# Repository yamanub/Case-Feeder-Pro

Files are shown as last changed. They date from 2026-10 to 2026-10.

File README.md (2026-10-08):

# Case Feeder Pro

Firmware for an automatic brass case feeder, a bullet feeder, or both run
side by side from one controller, with a touchscreen to control them.

- **Controller:** BigTreeTech SKR Pico V1.0 (RP2040). It drives the feeder
  motors, watches the part sensors, detects and clears jams, and stores
  the settings.
- **Touchscreen:** LCDWiki ES3C28P 2.8" ESP32-S3 display. It shows each
  feeder's state, speed and rate, sounds alerts, and holds the settings.

## The feeders

### Case feeder

<p>
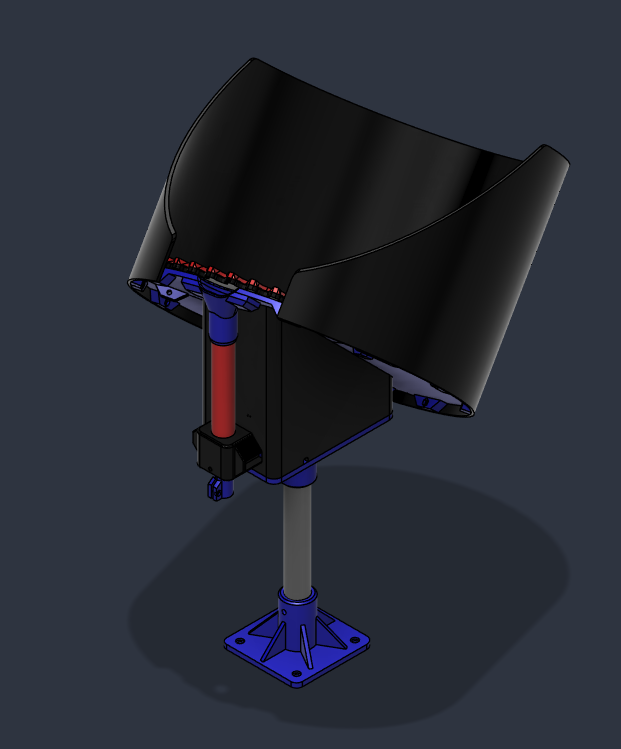
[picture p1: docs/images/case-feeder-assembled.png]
Case feeder on its stand
  
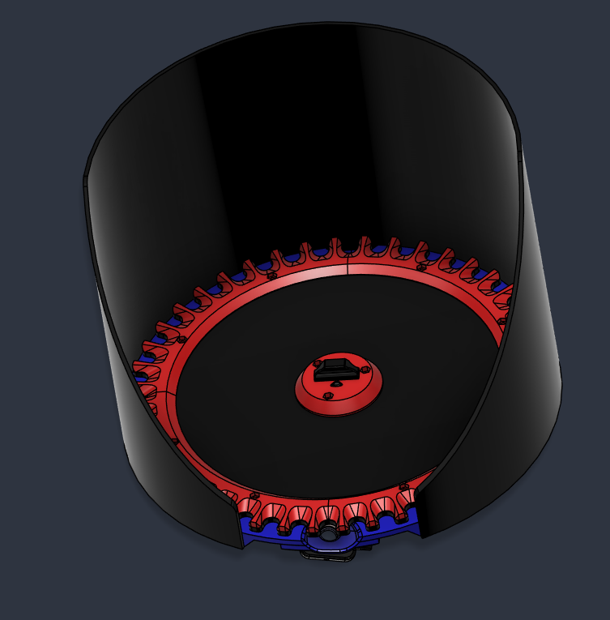
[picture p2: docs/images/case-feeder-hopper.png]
Case feeder hopper and plate
  
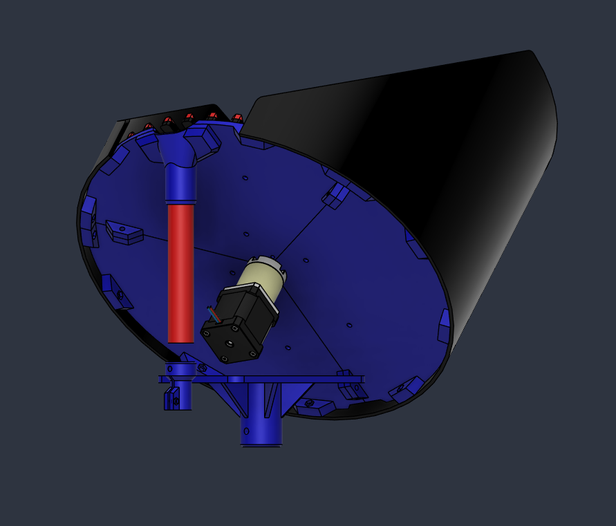
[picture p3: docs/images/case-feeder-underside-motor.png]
Case feeder underside with the 51:1 motor and exit tube
  
</p>
<p>
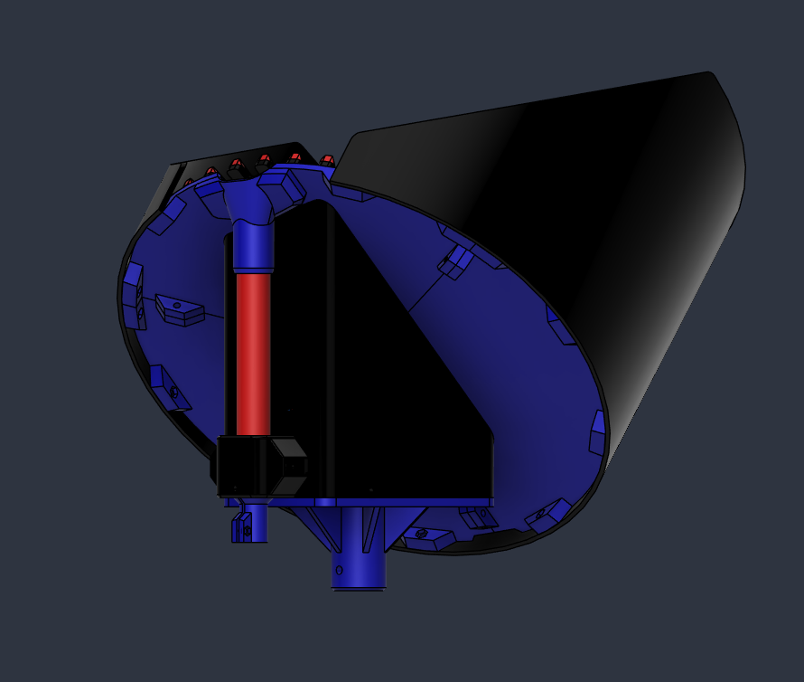
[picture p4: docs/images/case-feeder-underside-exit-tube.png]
Case feeder underside with the exit tube
  
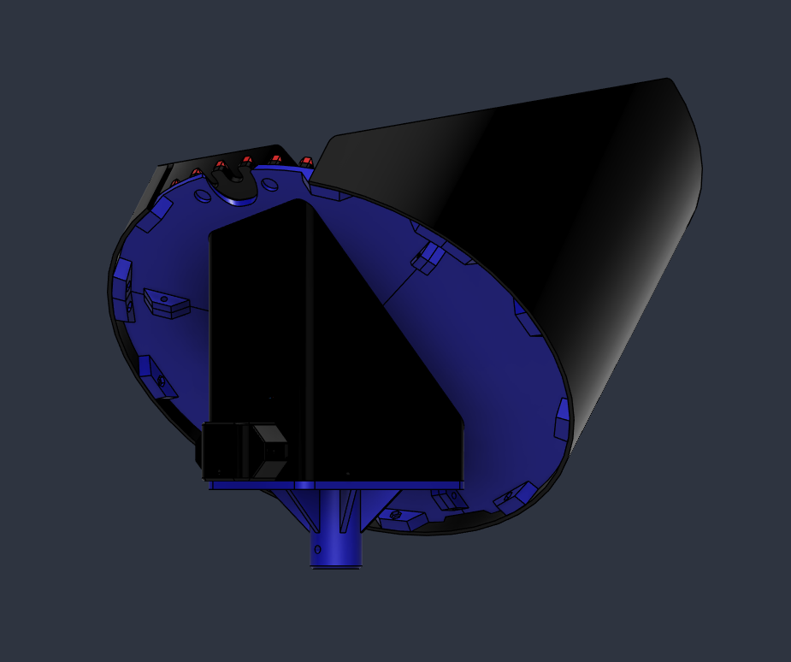
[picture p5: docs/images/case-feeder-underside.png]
Case feeder underside, enclosure closed
  
</p>

### Bullet feeder

<p>
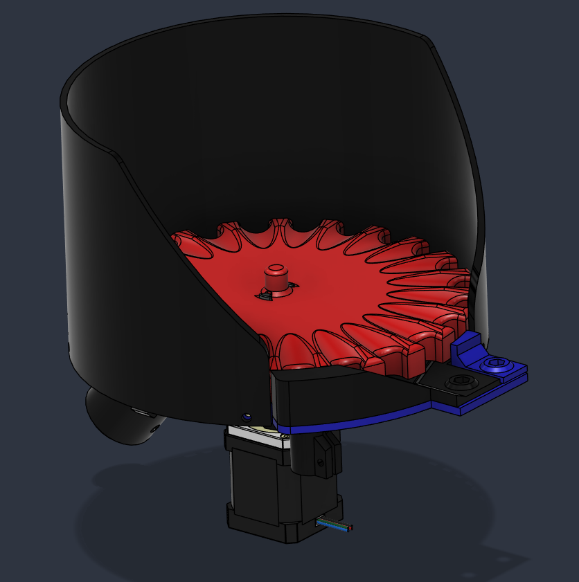
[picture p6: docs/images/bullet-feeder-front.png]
Bullet feeder, front view
  
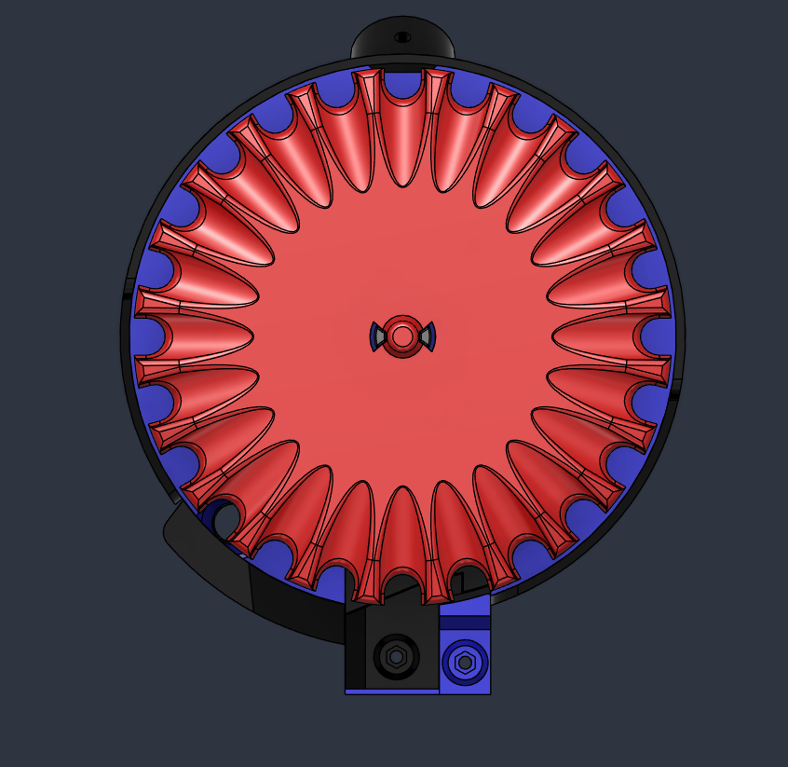
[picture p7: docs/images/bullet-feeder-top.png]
Bullet feeder plate, top view
  
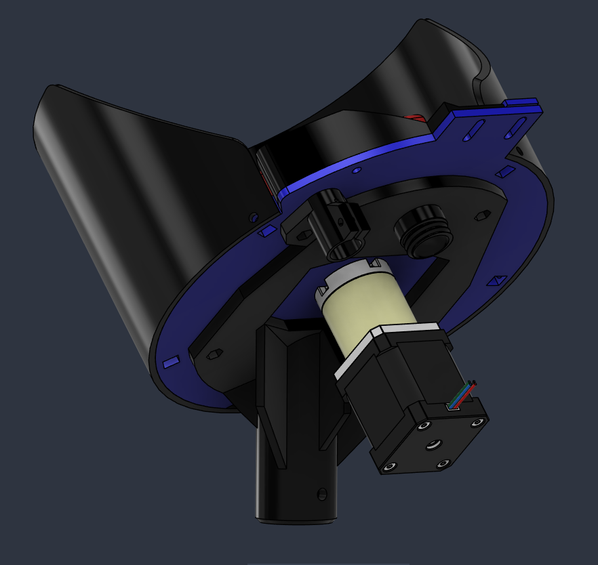
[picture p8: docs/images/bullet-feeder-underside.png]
Bullet feeder underside with the 51:1 motor
  
</p>

### Controller case

The SKR Pico and the touchscreen share one case, with the power switch,
power jack and driver fan on its end panel.

<p>
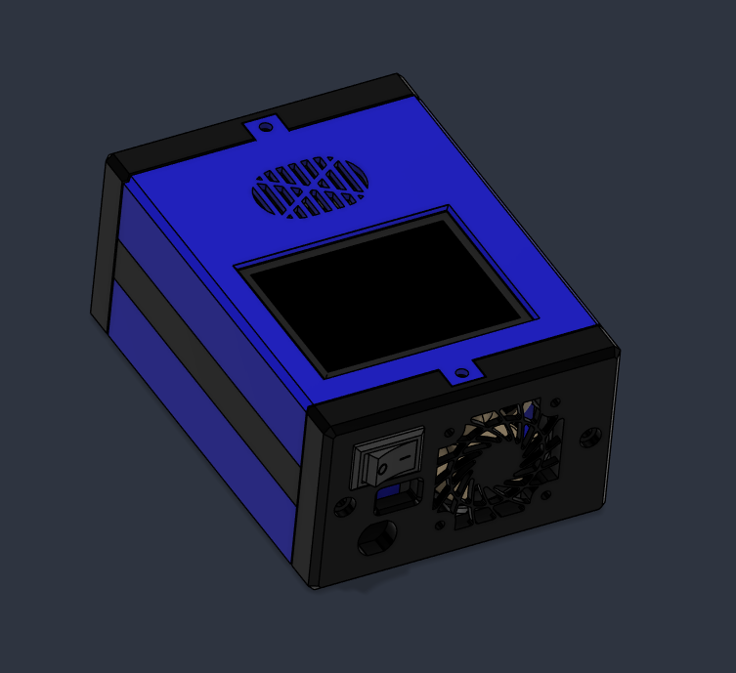
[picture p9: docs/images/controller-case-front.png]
Controller case, front: touchscreen, power switch, power jack and fan
  
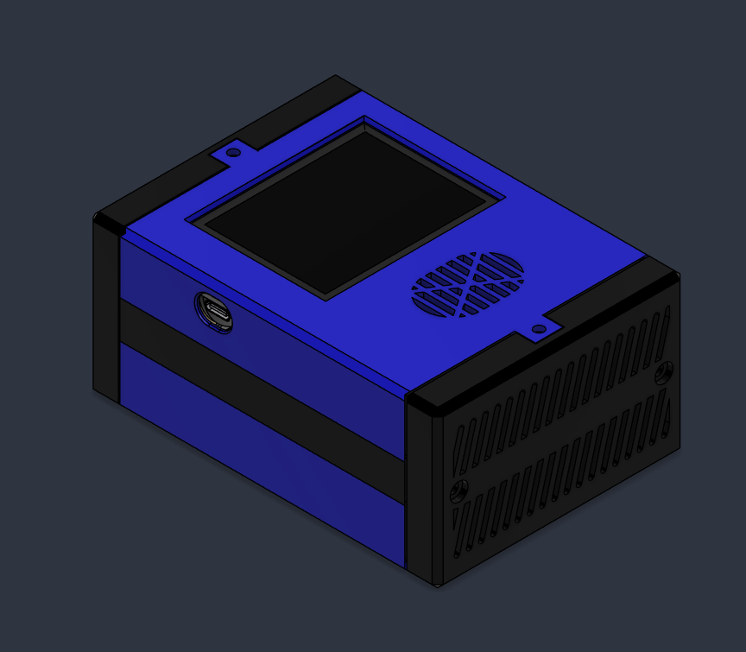
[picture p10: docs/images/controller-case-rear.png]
Controller case, rear: vents and USB-C port
  
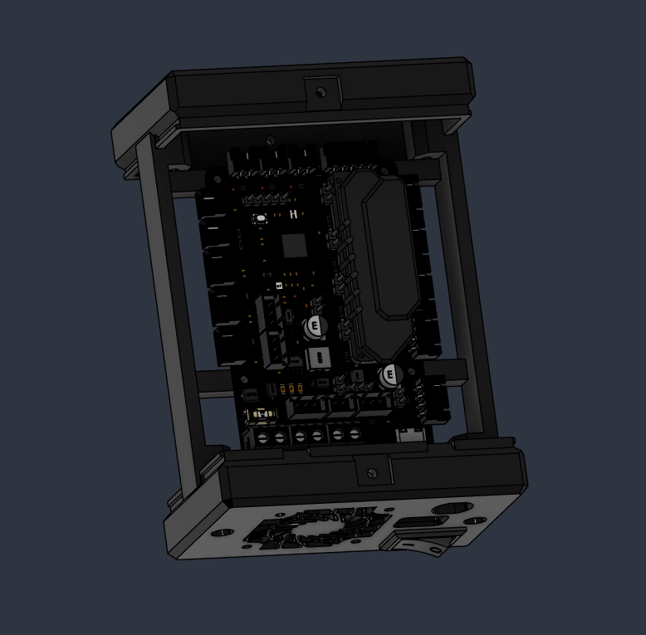
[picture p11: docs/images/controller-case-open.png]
Controller case open, SKR Pico inside
  
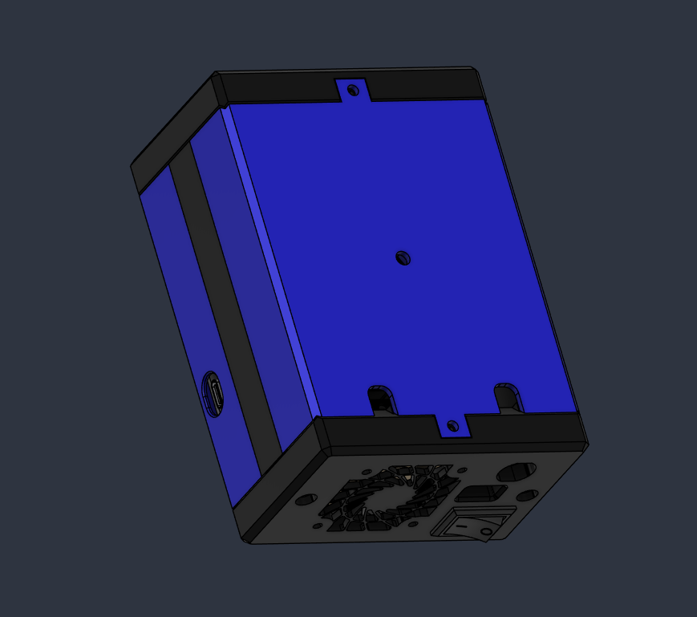
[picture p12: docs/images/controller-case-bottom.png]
Controller case, bottom with mounting slots
  
</p>

### Exploded views

How the printed parts go together. The case feeder is shown with and without
its ABS outer wall; see [printed parts](docs/PRINTED_PARTS.md) for every file.

To turn them around and pull the parts apart yourself, open the
**[interactive 3D viewer](https://yamanub.github.io/Case-Feeder-Pro/viewer/)**
(the page is [`docs/viewer/`](docs/viewer/index.html) in this repository).

<p>
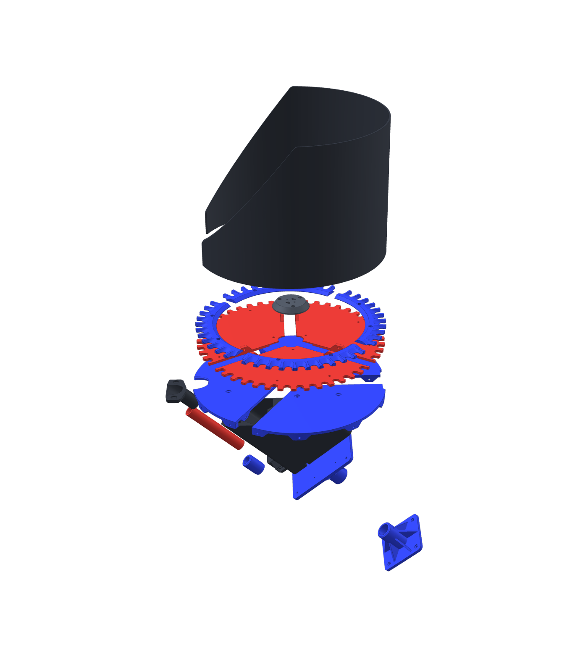
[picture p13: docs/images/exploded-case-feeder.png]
Case feeder exploded view: outer wall, plate sections, ramps, coupler, bowl floor, base, stand and exit
  
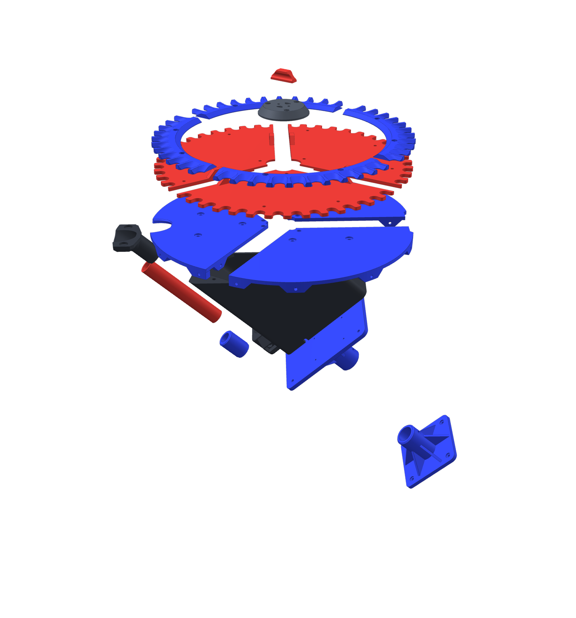
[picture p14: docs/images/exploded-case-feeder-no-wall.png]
Case feeder exploded view without the outer wall
  
</p>
<p>
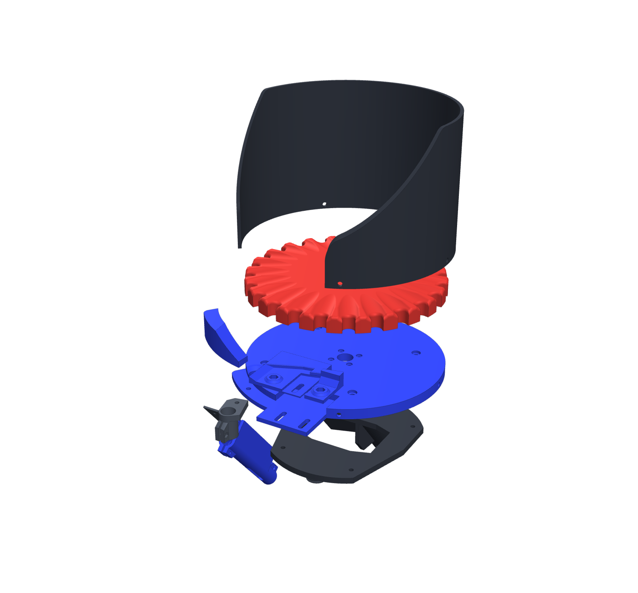
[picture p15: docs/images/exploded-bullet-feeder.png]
Bullet feeder exploded view: outer shell, plate, ramp and guides, main body, base and die bracket
  
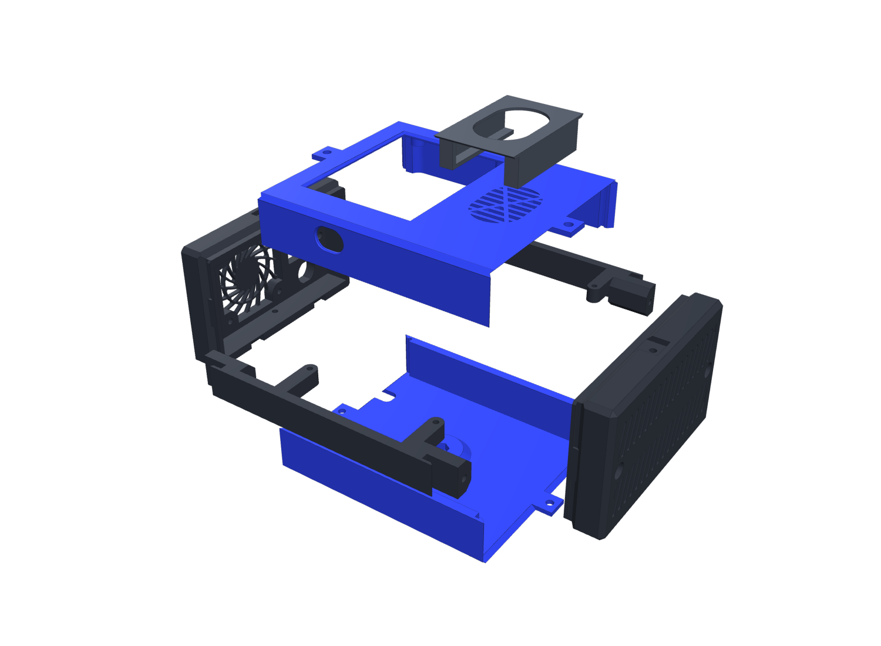
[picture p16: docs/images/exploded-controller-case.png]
Controller case exploded view: lids, sides, end caps and speaker housing
  
</p>

## Features

- **One firmware, three machines:** case feeder, bullet feeder, or dual
  (both). Choose on the touchscreen; no rewiring, since each feeder has its
  own ports.
- **Beam hold:** the motor stops while a part waits at the sensor and restarts
  when it is taken.
- **Jam detection and recovery:** sensorless stall detection (TMC2209
  StallGuard) reverses the plate to clear a jam, then feeds forward again. A
  jam that returns right away stops the feeder and raises an alarm.
- **Empty warning and auto shutoff** when nothing has fed for a while.
- **Five speed presets** per feeder, a live parts-per-hour rate, board
  temperature and motor-driver temperature alerts.
- **Independent feeders:** in dual mode a jam or stop on one never affects
  the other.
- The feeders keep running if the touchscreen is unplugged.

## Getting started

- [Build guide](docs/BUILD_GUIDE.md): wiring, flashing, first setup and
  daily use.
- [Parts list](docs/PARTS_LIST.md)
- [Printed parts](docs/PRINTED_PARTS.md): STL files for the feeders and the controller case

Both firmware images build with [PlatformIO](https://platformio.org/):

```
pio run -e controller -t upload
pio run -e lcd -t upload
```

## Repository layout

| Path | Contents |
|---|---|
| `src/controller.cpp` | controller firmware (SKR Pico) |
| `src/lcd_terminal.cpp` | touchscreen firmware (ESP32-S3) |
| `src/feeder_protocol.h` | the UART protocol shared by both |
| `src/*.h` | display, touch, audio and LVGL configuration for the touchscreen |
| `lib/FT6336/` | touch controller driver |
| `docs/` | build guide, parts list, printed parts, and the 3D viewer (`docs/viewer/`) |
| `stl/` | 3D-printable parts plus DXF and STEP files for cut and machined parts, one folder per assembly |

## License

- **Firmware and documentation:** GNU General Public License v3.0. See
  [LICENSE](LICENSE).
- **3D models and CAD files (`stl/`, and the viewer's copies in `docs/viewer/models/`):**
  Creative Commons Attribution-NonCommercial-ShareAlike 4.0 (CC BY-NC-SA 4.0).
  See [stl/LICENSE.md](stl/LICENSE.md).

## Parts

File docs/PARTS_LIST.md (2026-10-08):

# Parts list

Quantities are for one controller. "Per feeder" items are needed once for a
case or bullet feeder and twice for a dual setup.

## Controller and touchscreen

| Part | Qty | Notes | Link |
|---|---|---|---|
| BigTreeTech SKR Pico V1.0 | 1 | controller | [Amazon](https://a.co/d/09xAvw5X) |
| LCDWiki ES3C28P 2.8" ESP32-S3 display | 1 | touchscreen | [Amazon](https://www.amazon.com/dp/B0FKG7WRWV) |
| 24 V fan | 1 | driver cooling, on FAN1; required for dual | [Amazon](https://www.amazon.com/dp/B0757RPCN9) |
| WS2812 RGB LED | 1 | optional external status light | |

## Power

| Part | Qty | Notes | Link |
|---|---|---|---|
| 24 V power supply, 3 to 6 A | 1 | 3 A or more; the linked one is 3 A | [Amazon](https://www.amazon.com/dp/B078RY7BPL) |
| Power jack | 1 | | [Amazon](https://www.amazon.com/dp/B0D9B7WR23) |
| Power switch | 1 | | [Amazon](https://www.amazon.com/dp/B07S2QJKTX) |

## Feeder drive

| Part | Qty | Notes | Link |
|---|---|---|---|
| NEMA 17 stepper motor, 51:1 gearbox | per feeder | | [Amazon](https://www.amazon.com/dp/B00QEVLDVO) |
| Shaft coupler | 1 | only half of a coupler is used per feeder, so one coupler covers a dual build | [Amazon](https://www.amazon.com/dp/B08QVKMDC6) |

## Part sensor (one per feeder)

The case feeder uses the break-beam sensor; the bullet feeder uses the TCRT5000.

| Part | Qty | Notes | Link |
|---|---|---|---|
| TCRT5000 infrared reflective sensor | per bullet feeder | IR sensor: one unit. Bullet feeder only | [Amazon](https://www.amazon.com/dp/B00LZV1V10) |
| IR break-beam sensor | per case feeder | emitter + receiver pair. Case feeder only | [Amazon](https://www.amazon.com/dp/B0FPCR98F2) |

## Wiring

| Part | Qty | Notes | Link |
|---|---|---|---|
| JST-XH 2.54 mm connector kit, pre-crimped wires | 1 | the SKR Pico uses JST-XH connectors; cables need to be made (see the [build guide](BUILD_GUIDE.md#connectors-and-cables)) | [Amazon](https://www.amazon.com/dp/B0H3WK88ZL) |
| Motor cable, 4-pin | per feeder | | |
| Sensor cable, 3-wire | per feeder | | |
| Touchscreen cable, 4-wire | 1 | 5V, GND, TX, RX; comes with the touchscreen. Re-pin its Dupont end into a 5-pin JST-XH housing for the SKR Pico | |
| 470 Ω resistor | 2 | one in series with each touchscreen data wire | |
| Clip-on ferrite core | 1 | on the touchscreen cable | |
| USB-C cable | 1 | for flashing both boards | |

## Controller case hardware

| Part | Qty | Notes | Link |
|---|---|---|---|
| M3 x 12 mm button head screw | 4 | | |
| M3 x 4 mm button head screw | 4 | | |

## Case feeder hardware

Quantities for one case feeder.

| Part | Qty | Notes | Link |
|---|---|---|---|
| M4 x 10 mm screw | 31 | | [Amazon](https://www.amazon.com/dp/B0G19FJ4NV) (assorted lengths) |
| M4 x 16 mm screw | 6 | | [Amazon](https://www.amazon.com/dp/B0G19FJ4NV) (assorted lengths) |
| M4 nut | 24 | | [Amazon](https://www.amazon.com/dp/B0F8GGH5GX) |
| M4 heat-set insert | 11 | standard | |
| M3 x 12 mm button head screw | 6 | | |
| M3 x 6 mm button head screw | 2 | | |
| 3/4" PEX tubing | about 138 mm | feeder exit tube; cut to the length of `PEX Tube.stl` | |
| Magnet, 12 x 3 mm | 2 | feeder exit tube assembly | [Amazon](https://www.amazon.com/dp/B0CCVPVQ1L) |
| ABS sheet, 1/16" thick, 24" x 48" | 1 | outer wall of the feeder; cut from `ABS Outer v5 Flat.dxf` (932 x 250 mm) | [Amazon](https://www.amazon.com/dp/B0C7QG8463) |
| ABS sheet, 3/16" thick (optional) | 1 | to mill the one-piece feeder plate instead of printing the three-piece plate; a STEP model is provided for CNC machining (see [printed parts](PRINTED_PARTS.md)). The reference build milled it from this sheet | |

## Bullet feeder hardware

Quantities for one bullet feeder.

| Part | Qty | Notes | Link |
|---|---|---|---|
| M4 x 10 mm screw | 7 | | [Amazon](https://www.amazon.com/dp/B0G19FJ4NV) (assorted lengths) |
| M4 x 16 mm screw | 6 | | [Amazon](https://www.amazon.com/dp/B0G19FJ4NV) (assorted lengths) |
| M4 nut | 12 | | [Amazon](https://www.amazon.com/dp/B0F8GGH5GX) |
| M3 x 12 mm button head screw | 3 | | |
| M3 x 6 mm button head screw | 3 | | |
| M3 nut | 3 | | |
| ABS sheet, 1/16" thick, 24" x 48" | 1 | outer wall of the feeder; cut from `ABS outer shell Wrap Flat.dxf` (487 x 127 mm) | [Amazon](https://www.amazon.com/dp/B0C7QG8463) |

The two outer walls together use about 932 x 250 mm plus 487 x 127 mm, so
one 24" x 48" ABS sheet covers both the case feeder and the bullet feeder,
with room to spare. A dual build needs only one sheet.

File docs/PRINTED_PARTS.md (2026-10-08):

# Printed parts

STL files (and the DXF and STEP files for cut and machined parts) are in
[`stl/`](../stl), one folder per assembly. Sizes are the
part's bounding box in millimetres, as exported. The models are licensed
under [CC BY-NC-SA 4.0](../stl/LICENSE.md): non-commercial use, with credit,
and modified versions shared under the same license.

## Case feeder ([`stl/case-feeder`](../stl/case-feeder))

Case feeder exploded view

The largest parts are about 292 mm long, so the case feeder needs a printer
with a bed of at least **300 x 300 mm**.

### Feeder plate (choose one)

| File | Size (mm) | Notes |
|---|---|---|
| `Feeder Plate Printed 1.stl` | 291 x 163 x 14 | printed plate, section 1 of 3 |
| `Feeder Plate Printed 2.stl` | 166 x 268 x 14 | printed plate, section 2 of 3 |
| `Feeder Plate Printed 3.stl` | 179 x 226 x 14 | printed plate, section 3 of 3 |
| `ABS Feeder Plate Milled.stl` | 334 x 334 x 4.4 | one-piece plate, milled from 3/16" ABS sheet (see the [parts list](PARTS_LIST.md)) |
| `ABS Feeder Plate Milled.step` | 334 x 334 x 4.4 | the same one-piece plate as a STEP model, for CNC machining |

| File | Size (mm) | Notes |
|---|---|---|
| `Feeder Plate Ramp V7.stl` | 167 x 167 x 6 | print 4 |

### Bowl (choose one)

Three-piece bowl, fits a 300 x 300 mm bed:

| File | Size (mm) | Notes |
|---|---|---|
| `Left Bowl V5.stl` | 170 x 202 x 173 | |
| `Mid Bowl V5.stl` | 292 x 124 x 128 | |
| `Right Bowl V5.stl` | 170 x 173 x 207 | |

One-piece bowl, for large-format printers:

| File | Size (mm) | Notes |
|---|---|---|
| `1 piece Bowl.stl` | 337 x 255 x 252 | replaces the three bowl pieces |

Outer wall (either bowl):

| File | Size (mm) | Notes |
|---|---|---|
| `ABS Outer v5.stl` | 387 x 317 x 420 | shape of the outer wall, cut from 1/16" ABS sheet; not printed |
| `ABS Outer v5 Flat.dxf` | 932 x 250 (flat) | cutting pattern for the outer wall, full size in millimetres, with the 12 screw holes along the bottom edge |

### Base and mounting

| File | Size (mm) | Notes |
|---|---|---|
| `Base V5 Angle.stl` | 100 x 196 x 196 | |
| `Base Mount v5 Center.stl` | 100 x 61 x 162 | base mount, centered (choose this or Offset) |
| `Base Mount v5 Offset.stl` | 100 x 61 x 162 | base mount, offset (choose this or Center) |
| `Table Mount v5.stl` | 100 x 61 x 102 | |

### Motor coupler

| File | Size (mm) | Notes |
|---|---|---|
| `Coupler Attachment Top V7.stl` | 70 x 70 x 11 | |
| `Coupler Attachment Bottom V7.stl` | 70 x 70 x 12 | |
| `Coupler Attachment Handle.stl` | 10 x 35 x 14 | |

### Exit

| File | Size (mm) | Notes |
|---|---|---|
| `Feeder Exit.stl` | 77 x 69 x 36 | |
| `PEX Tube.stl` | 22 x 138 x 22 | length guide, not printed: the real part is 3/4" PEX tubing cut to this length (about 138 mm) |

Funnel exit (choose the one that matches your drop tube):

| File | Size (mm) | Notes |
|---|---|---|
| `Funnel Exit Dillon Tube.stl` | 27 x 30 x 27 | Dillon drop tube |
| `Funnel Exit PEX.stl` | 27 x 38 x 27 | PEX tube |
| `Funnel Exit Rollsizer Tube.stl` | 27 x 38 x 27 | Rollsizer tube |
| `Funnel Exit spring 15mm.stl` | 27 x 41 x 28 | 15 mm spring |

## Bullet feeder ([`stl/bullet-feeder`](../stl/bullet-feeder))

Bullet feeder exploded view

The largest part is about 220 mm.

| File | Size (mm) | Notes |
|---|---|---|
| `Main Body.stl` | 191 x 10 x 220 | |
| `Base Mount.stl` | 131 x 71 x 192 | |
| `Base Spring Connector.stl` | 27 x 27 x 42 | |
| `Ramp.stl` | 63 x 23 x 50 | |
| `Guide.stl` | 51 x 6 x 53 | |
| `Guide Stop.stl` | 18 x 13 x 35 | |
| `ABS outer shell Wrap.stl` | 198 x 127 x 193 | shape of the outer wall, cut from 1/16" ABS sheet; not printed |
| `ABS outer shell Wrap Flat.dxf` | 487 x 127 (flat) | cutting pattern for the outer wall, full size in millimetres, with the 5 screw holes along the bottom edge |

Feeder plate (choose your caliber):

| File | Size (mm) | Notes |
|---|---|---|
| `Feeder Plate 9mm.stl` | 188 x 29 x 188 | 9 mm |
| `Feeder Plate 45ACP.stl` | 188 x 29 x 188 | .45 ACP |

Die bracket and cover (choose your press and caliber):

| File | Size (mm) | Notes |
|---|---|---|
| `Dillon Die Bracket 9.stl` | 19 x 115 x 99 | Dillon, 9 mm |
| `Dillon Die Bracket-45.stl` | 19 x 116 x 99 | Dillon, .45 |
| `DAA Die Bracket 9.stl` | 19 x 115 x 99 | DAA, 9 mm |
| `Die Bracket Cover 9.stl` | 19 x 81 x 63 | 9 mm |
| `Die Bracket Cover-45.stl` | 19 x 81 x 63 | .45 |

## Controller case ([`stl/controller-case`](../stl/controller-case))

Controller case exploded view

Holds the SKR Pico and the touchscreen.

| File | Size (mm) | Notes |
|---|---|---|
| `CFBF Top Cap.stl` | 17 x 90 x 57 | |
| `CFBF Bottom Cap.stl` | 17 x 90 x 57 | |
| `CFBF Center Side 1.stl` | 118 x 23 x 14 | |
| `CFBF Center Side 2.stl` | 118 x 23 x 14 | |
| `CFBF LCD Lid.stl` | 118 x 90 x 21 | touchscreen side |
| `CFBF Pico Lid.stl` | 118 x 90 x 22 | SKR Pico side |
| `CFBF Speaker Housing.stl` | 32 x 47 x 13 | |

## Case arm mount ([`stl/case-arm-mount`](../stl/case-arm-mount))

The arm that attaches the controller case to the case feeder or the bullet
feeder.

| File | Size (mm) | Notes |
|---|---|---|
| `Arm - BoltSide.stl` | 42 x 15 x 15 | |
| `Arm - NutSide.stl` | 42 x 15 x 15 | |
| `Ball End.stl` | 18 x 20 x 18 | |
| `Ball Nut.stl` | 30 x 12 x 30 | |
| `Screw Attachment.stl` | 23 x 13 x 23 | attaches the case arm to the feeder |

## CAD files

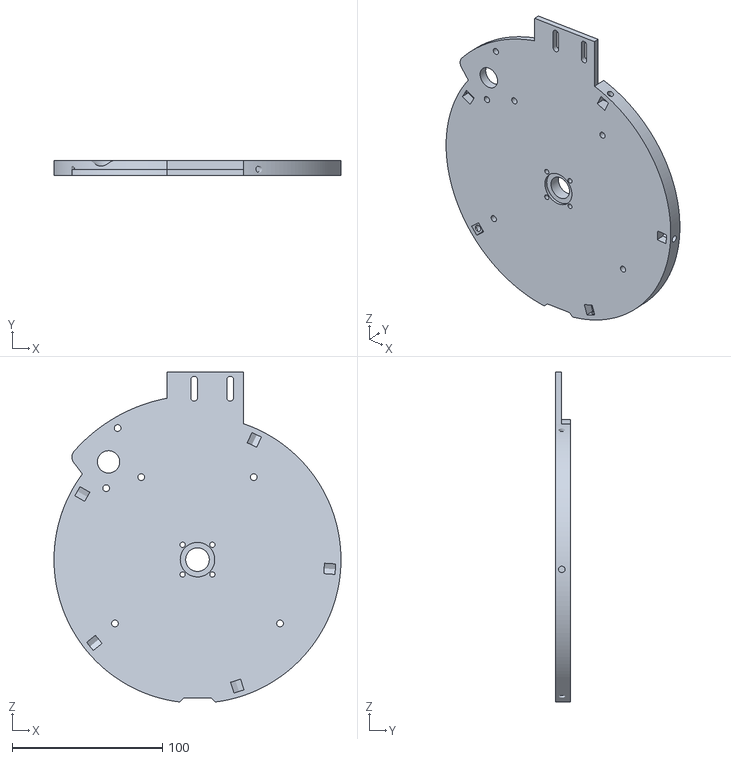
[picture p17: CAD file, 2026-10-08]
docs/viewer/models/bullet/main-body.stl
191.2 x 10.0 x 219.9

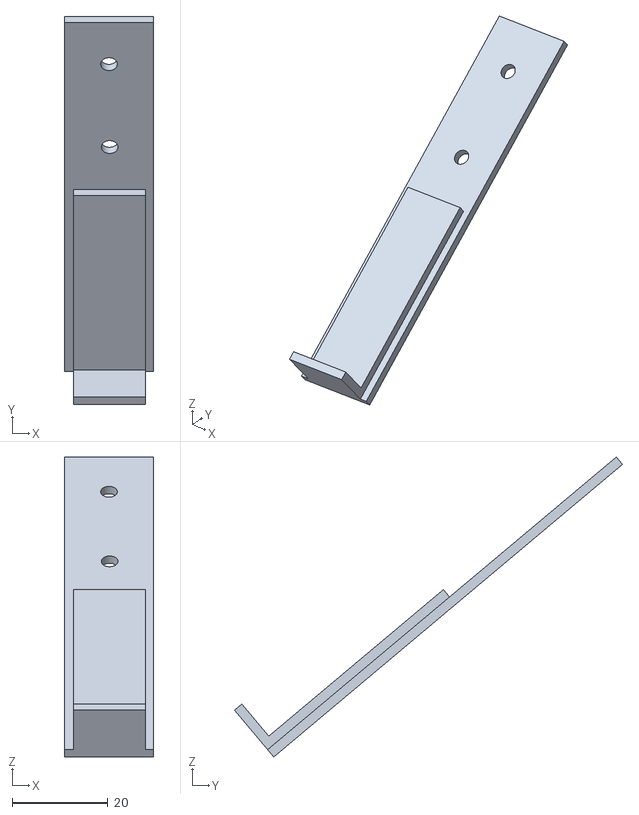
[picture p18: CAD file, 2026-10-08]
docs/viewer/models/bullet/die-bracket-cover-9.stl
18.6 x 81.0 x 62.6

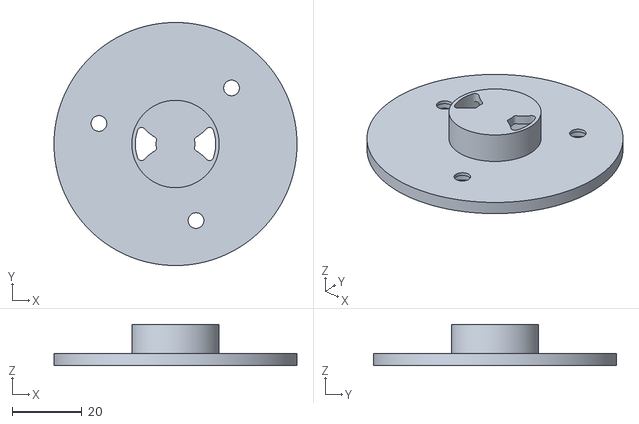
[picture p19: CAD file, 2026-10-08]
docs/viewer/models/case/coupler-bottom.stl
69.5 x 69.5 x 11.8

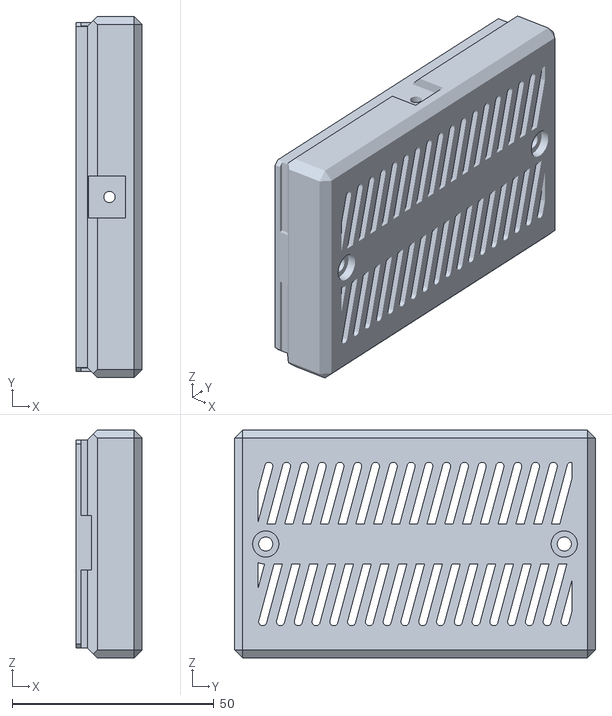
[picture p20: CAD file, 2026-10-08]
docs/viewer/models/controller/cfbf-top-cap.stl
16.5 x 89.6 x 56.5

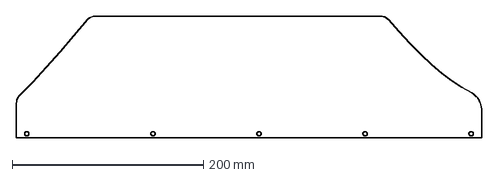
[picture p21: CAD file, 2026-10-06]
stl/bullet-feeder/ABS outer shell Wrap Flat.dxf
486.7 x 127.0 mm

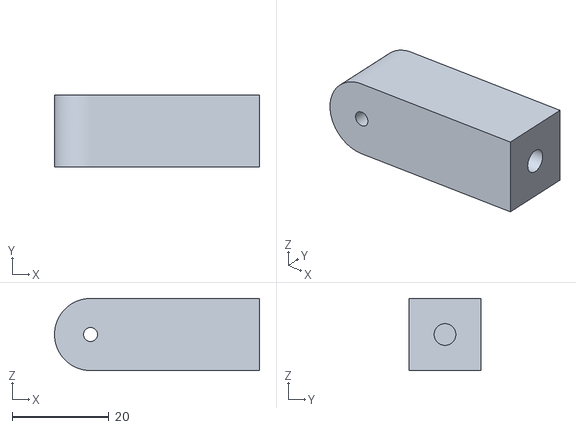
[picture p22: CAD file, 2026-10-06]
stl/case-arm-mount/Arm - NutSide.stl
42.4 x 14.9 x 14.9

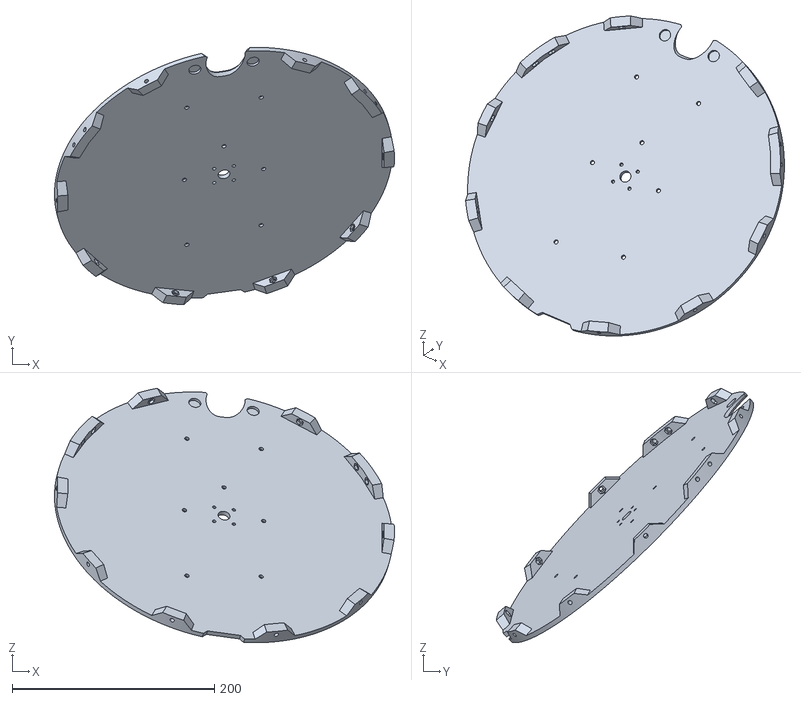
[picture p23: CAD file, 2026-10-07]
stl/case-feeder/1 piece Bowl.stl
336.6 x 254.9 x 251.9

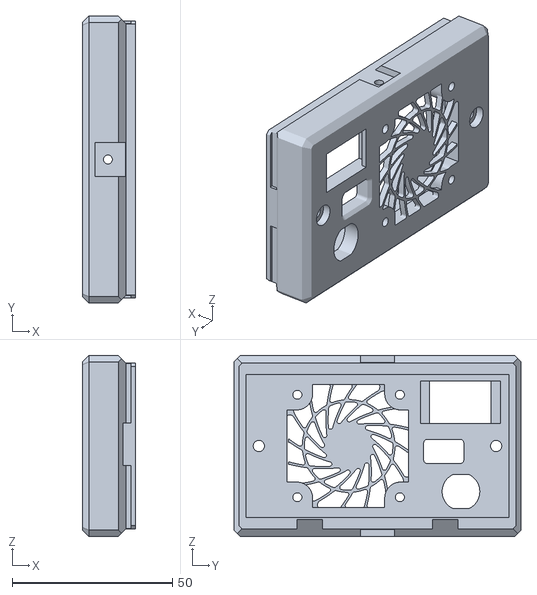
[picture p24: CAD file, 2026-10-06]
stl/controller-case/CFBF Bottom Cap.stl
16.5 x 89.6 x 56.5

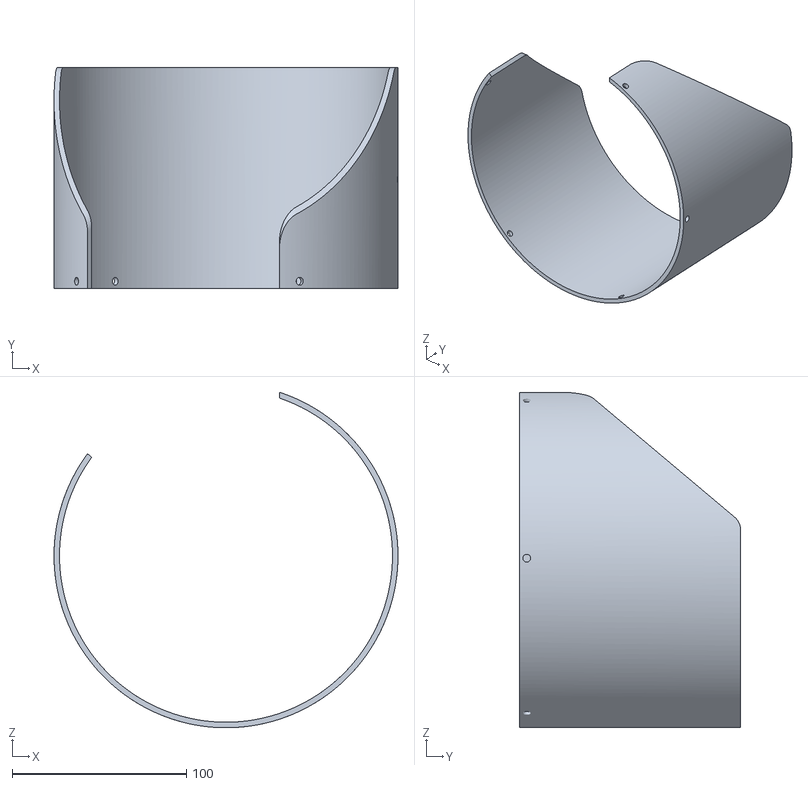
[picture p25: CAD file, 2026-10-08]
docs/viewer/models/bullet/abs-outer-shell-wrap.stl
197.5 x 127.0 x 192.6

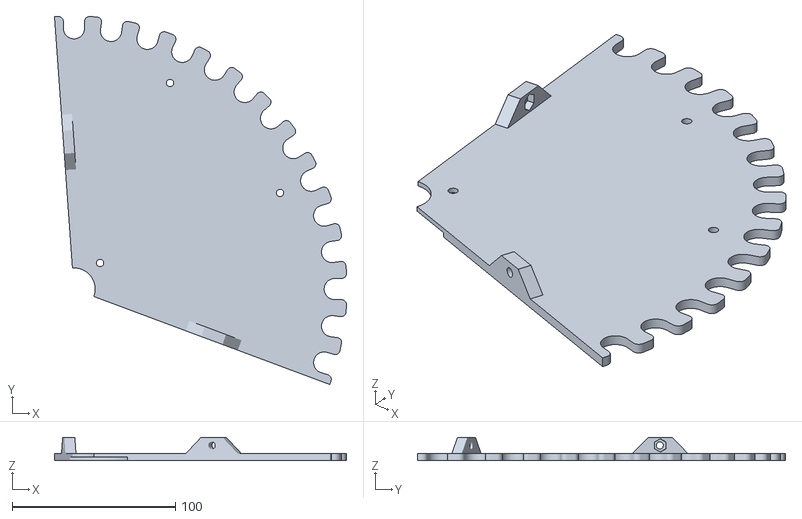
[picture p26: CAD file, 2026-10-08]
docs/viewer/models/case/plate-3.stl
179.2 x 225.8 x 14.4

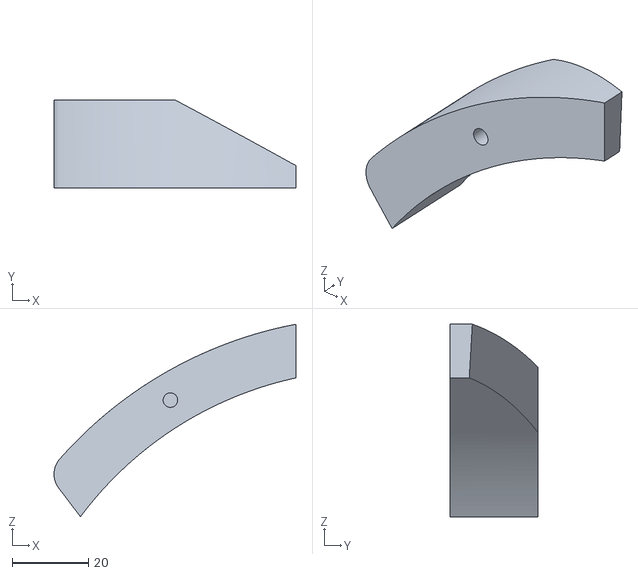
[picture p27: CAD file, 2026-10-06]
stl/bullet-feeder/Ramp.stl
63.3 x 23.1 x 50.4

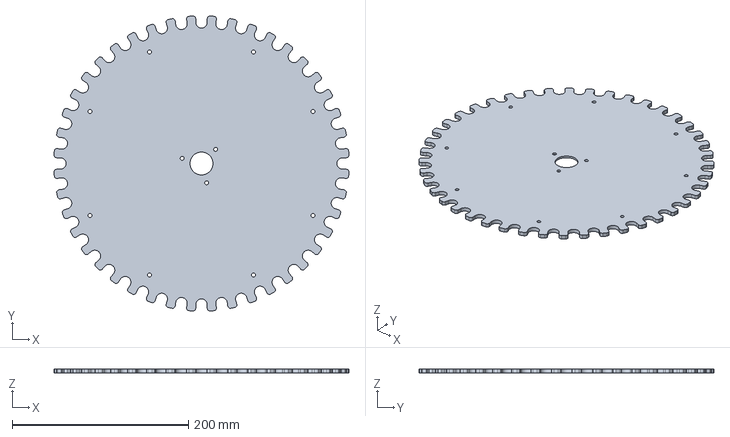
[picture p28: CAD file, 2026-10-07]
stl/case-feeder/ABS Feeder Plate Milled.step
334.4 x 334.4 x 4.40 mm

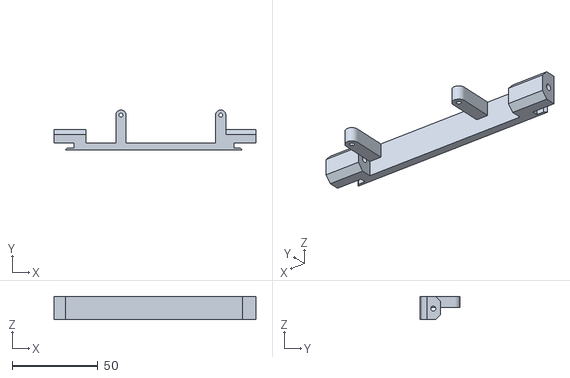
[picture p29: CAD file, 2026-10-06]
stl/controller-case/CFBF Center Side 2.stl
117.5 x 23.3 x 13.6

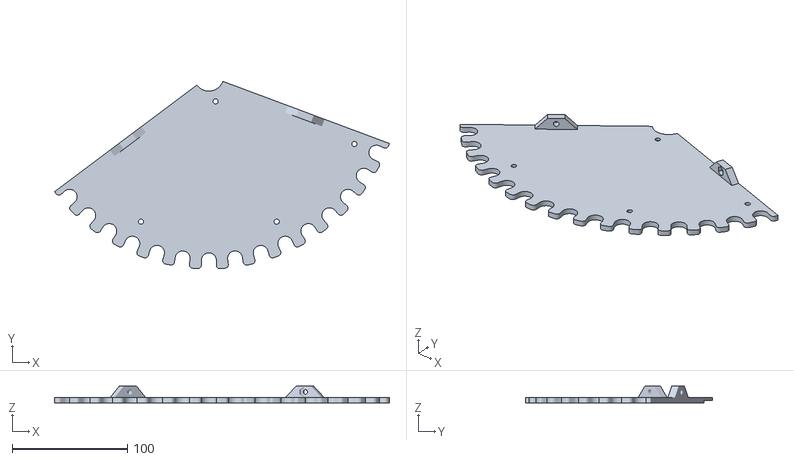
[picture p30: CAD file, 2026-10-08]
docs/viewer/models/case/plate-1.stl
291.0 x 162.7 x 14.4

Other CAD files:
stl/bullet-feeder/Main Body.stl
docs/viewer/models/controller/cfbf-bottom-cap.stl
docs/viewer/models/bullet/ramp.stl
docs/viewer/models/controller/cfbf-speaker-housing.stl
docs/viewer/models/bullet/base-mount.stl
docs/viewer/models/bullet/base-spring-connector.stl
docs/viewer/models/bullet/dillon-die-bracket-9.stl
docs/viewer/models/bullet/feeder-plate-9mm.stl
docs/viewer/models/bullet/guide-stop.stl
docs/viewer/models/bullet/guide.stl
docs/viewer/models/case/base-angle.stl
docs/viewer/models/case/base-mount.stl
docs/viewer/models/case/bowl-left.stl
docs/viewer/models/case/bowl-mid.stl
docs/viewer/models/case/bowl-right.stl
docs/viewer/models/case/coupler-handle.stl
docs/viewer/models/case/coupler-top.stl
docs/viewer/models/case/exit.stl
docs/viewer/models/case/funnel.stl
docs/viewer/models/case/outer.stl
docs/viewer/models/case/pex.stl
docs/viewer/models/case/plate-2.stl
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

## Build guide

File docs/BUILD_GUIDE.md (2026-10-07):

# Build guide

This guide covers wiring the controller and touchscreen, flashing the
firmware, first setup, and day-to-day use. For the parts, see the
[parts list](PARTS_LIST.md).

1. [How it fits together](#how-it-fits-together)
2. [Controller wiring](#controller-wiring)
3. [Touchscreen wiring](#touchscreen-wiring)
4. [Flashing the firmware](#flashing-the-firmware)
5. [First setup](#first-setup)
6. [Using the feeder](#using-the-feeder)
7. [Serial commands](#serial-commands)
8. [Adjusting jam detection](#adjusting-jam-detection)
9. [Troubleshooting](#troubleshooting)

---

## How it fits together

- The **controller** (BTT SKR Pico V1.0) runs everything that moves: the
  feeder motors, the part sensors, jam detection and the saved
  settings. It runs a **case feeder**, a **bullet feeder**, or **both**.
- The **touchscreen** (LCDWiki ES3C28P) connects to the controller with a
  4-wire cable. It shows each feeder, sends your commands, and plays the
  alert sounds. The feeders keep running if it is unplugged.
- Each feeder has **fixed ports** on the controller. Which feeders the
  controller runs is the **Machine** setting, chosen on the touchscreen, so
  you never rewire to change it.

## Controller wiring

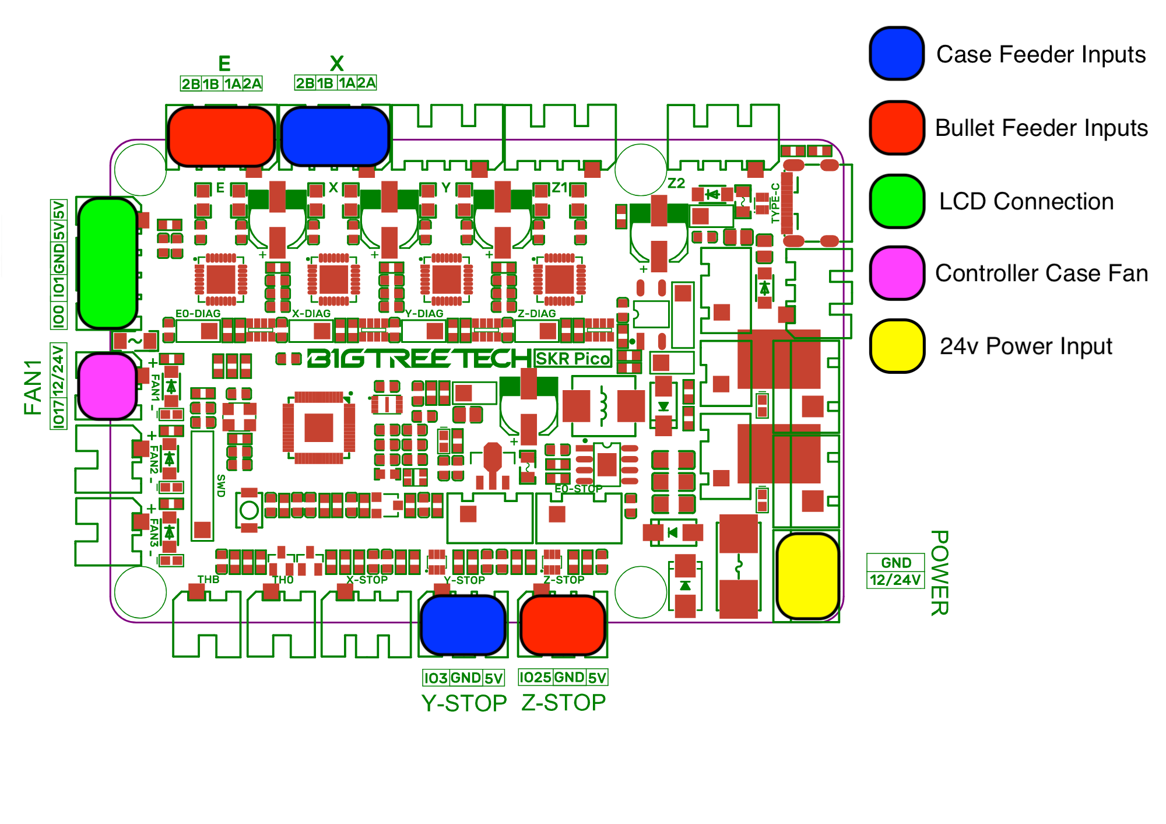
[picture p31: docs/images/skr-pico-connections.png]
SKR Pico connections: case feeder blue, bullet feeder red, touchscreen green, fan pink, 24 V power yellow


*Board drawing based on the BigTreeTech SKR Pico V1.0 pin diagram.*

### Ports

| What | SKR Pico connector | Notes |
|---|---|---|
| 24 V supply | **POWER** screw terminal | +24 V to `12/24V`, 0 V to `GND` |
| Case feeder motor | **X** motor connector | |
| Case feeder sensor | **Y-STOP** (`IO3 / GND / 5V`) | see [Part sensors](#part-sensors) |
| Bullet feeder motor | **E** motor connector | |
| Bullet feeder sensor | **Z-STOP** (`IO25 / GND / 5V`) | see [Part sensors](#part-sensors) |
| Touchscreen | **Raspberry Pi UART** connector, 5-pin (`5V 5V GND IO1 IO0`) | see [Touchscreen wiring](#touchscreen-wiring) |
| Driver fan | **FAN1** | a **24 V** fan; FAN1 switches the 24 V input. Required when running two feeders |
| Status light (optional) | **RGB** header (`GND / IO24 / 5V`) | a WS2812 LED; it mirrors the on-board RGB LED |
| USB-C | USB-C socket | flashing and the serial console |

Only wire the feeders you have: a case-only build uses X and Y-STOP, a
bullet-only build uses E and Z-STOP.

### Connectors and cables

The SKR Pico uses **JST-XH (2.54 mm pitch)** connectors: 4-pin on the motor
ports, 3-pin on the STOP and RGB ports, 2-pin on FAN1, and 5-pin on the Pi
UART connector for the touchscreen. Most of the parts do not
come with matching plugs, so plan to make your own cables. A JST-XH kit with
pre-crimped wires (see the [parts list](PARTS_LIST.md)) avoids the need for a
crimp tool.

| Part | What it comes with | What to do |
|---|---|---|
| Stepper motors | Dupont 2.54 mm plugs | these fit the motor ports; check the coil pairs (see [Motors](#motors)) |
| Driver fan | 2-pin JST-XH plug | plugs straight into FAN1 |
| Break-beam sensor | JST-XH plugs; one may be 2-pin | re-pin a 2-pin plug into a 3-pin housing to match the STOP connector |
| TCRT5000 IR sensor | header pins, no wires | make a 3-wire cable with a 3-pin JST-XH plug for the STOP connector |
| Touchscreen | a cable with a small 4-pin plug on the screen end and Dupont connectors on the other | re-pin the Dupont end into a 5-pin JST-XH housing for the Pi UART connector (one `5V` position stays empty), and add the series resistors (see [Touchscreen wiring](#touchscreen-wiring)) |

### Jumpers

Every board is jumpered the same way, whatever the machine:

| Jumper | Setting | Why |
|---|---|---|
| **X-DIAG** | **fitted** | connects the case motor driver's stall signal to X-STOP |
| **E0-DIAG** | **fitted** | connects the bullet motor driver's stall signal to E0-STOP |
| **Y-DIAG** | **removed** | would connect an unused driver to the case sensor input |
| **Z-DIAG** | **removed** | would connect an unused driver to the bullet sensor input |
| BOOT | only for the first flash | see [Flashing the firmware](#flashing-the-firmware) |

Leave the X-STOP and E0-STOP connectors themselves empty; with the jumpers
fitted they carry the stall signal.

### Motors

The motor connectors are printed `2B 1B 1A 2A`. The motor's two coils go on
**adjacent pins**: one coil on `2B`+`1B`, the other on `1A`+`2A`. If a motor
buzzes or shudders without turning, its coil pairs are wrong. If it turns
the wrong way, don't rewire; set the direction in software (see
[First setup](#first-setup)).

The motor current is fixed in the firmware at 0.95 A.

### Part sensors

Each feeder has one sensor at its outlet that sees each part go by. Two
types are used; both are 3-wire 5 V sensors. The case feeder uses the
break-beam sensor; the bullet feeder uses the IR sensor.

| Sensor type | Wiring to the feeder's STOP connector |
|---|---|
| **IR sensor** (one unit) | signal to `IO`, `5V`, `GND` |
| **Break-beam** (emitter + receiver) | **receiver**: signal to `IO`, `5V`, `GND`. **Emitter**: `5V` and `GND` only, shared with the receiver on the same connector |

The case feeder's sensor goes on **Y-STOP** (`IO3`), the bullet feeder's on
**Z-STOP** (`IO25`). The firmware calls the sensor the *beam*: "beam
blocked" means the sensor sees a part.

By default the firmware expects the signal to read **LOW while a part is
there**. A sensor that works the other way is set with one command during
[First setup](#first-setup).

## Touchscreen wiring

| SKR Pico Pi UART connector | Touchscreen UART connector |
|---|---|
| `5V` | `5V` |
| `GND` | `GND` |
| `IO0` (controller TX) | `GPIO44` (screen RX) |
| `IO1` (controller RX) | `GPIO43` (screen TX) |

- Wire the data lines **by GPIO number**. The printed labels on some
  display boards are reversed; if the screen shows **NO LINK**, swap the two
  data wires.
- Fit a **470 Ω resistor in series with each data wire**.
- **Twist each data wire with its own ground wire**, keep the cable short,
  and route it away from the motor cables.
- Clip a **ferrite core** onto the cable near the touchscreen.

## Flashing the firmware

### Software

1. Install [Visual Studio Code](https://code.visualstudio.com/) and its
   **PlatformIO IDE** extension.
2. Open this repository's folder in VS Code. PlatformIO downloads the
   toolchains and libraries on the first build.

Commands below are run in the PlatformIO terminal from the repository folder.

### Controller (SKR Pico)

1. Connect the SKR Pico to the computer with USB-C. **Unplug the
   touchscreen's USB cable** while you do this: with both boards connected,
   the upload can send its reset to the touchscreen instead of the SKR Pico.
2. **First flash only:** fit the **BOOT** jumper and press the reset button.
   The board appears as a USB drive named `RPI-RP2`.
3. Run:
   ```
   pio run -e controller -t upload
   ```
4. **First flash only:** remove the BOOT jumper and press reset.

After the first flash, the upload command resets the board into its
bootloader by itself; no jumper is needed.

### Touchscreen (ESP32-S3)

1. Connect the touchscreen to the computer with USB-C.
2. Run:
   ```
   pio run -e lcd -t upload
   ```
3. If the upload cannot connect, hold the board's **BOOT** button, press
   **RESET**, release BOOT, and run the command again.

### Serial console

Both boards print status over USB at 115200 baud:

```
pio device monitor -e controller
pio device monitor -e lcd
```

Type a command and press Enter. On the controller, `?` prints the full
status; on the touchscreen, `?` prints its link and screen state.

## First setup

Do this once per controller, with the plates empty.

1. **Power up.** Turn on 24 V. The controller's RGB LED is dim white when
   ready. The touchscreen shows a feeder screen; the bottom bar should read
   `LINKED` or a feeder state, not `NO LINK`.
2. **Choose the machine.** On the touchscreen, tap the gear (Settings), then
   **press and hold** the **Machine** button. Pick **CASE**, **BULLET** or
   **DUAL**; the popup shows the wiring that choice expects. Tap **APPLY**.
   The screen changes to match within a second. A new board starts as DUAL.
3. **Check the motor drivers.** Open the controller's serial console and
   send `?`. Each feeder should show `driver: ready, DIAG in use`. If it
   shows `DIAG NOT used`, that feeder's DIAG jumper is missing.
4. **Check each sensor.** Send `e 1` (beam log on), then block and unblock
   each sensor by hand. You should see `C BEAM broken` / `C BEAM cleared` for
   the case feeder and `B BEAM ...` for the bullet feeder. If a sensor reports
   *broken* when you unblock it, select that feeder (`U 0` case, `U 1`
   bullet) and send `N 1`. Send `e 0` when done.
5. **Check each motor's direction.** Tap **GO** for one feeder and watch the
   plate. If it turns the wrong way, tap **STOP**, select that feeder
   (`U 0` / `U 1`) and send `M 1`. Repeat for the other feeder.
6. **Test jam recovery.** Load the feeder and run it. Hold the plate by hand
   for about a second: the feeder should back up, pause, and feed forward
   again. Hold it again straight away: it should stop with a **STALL** popup
   and an alarm. Tap **RESUME**.

The machine, beam polarity, motor direction, feed speeds and empty-warning
times are saved on the controller. Alerts, volume, screen flip and the last screen
layout are saved on the touchscreen.

## Using the feeder

### The screen

**One feeder** (CASE FEEDER PRO or BULLET FEEDER PRO):

- **FEED SPEED:** tap a preset (20, 40, 60, 80, 100 %).
- **CASES/HR** (or BULLETS/HR): the live feed rate. Press and hold to reset
  it.
- **TEMP:** the controller board's temperature.
- **GO / STOP:** starts and stops the feeder.
- **Bottom bar:** the feeder's state, the most urgent message, and the
  firmware version.

**Two feeders** (DUAL FEEDER PRO): the left half is the case feeder, the
right half the bullet feeder. Each half has its state, a **FEED SPEED**
stepper (`-` / `+` move between the presets), the live rate (press and hold
to reset) and its own **GO / STOP**. The top bar shows the board
temperature and Settings; the bottom bar shows the link and the most urgent
message from either feeder. Popups name the feeder they belong to.

Each feeder remembers its last speed and starts there after power-up (60 %
on a new controller).

### What the feeder does on its own

- **Beam hold:** when a part sits at the sensor, the motor stops (state
  `CASE HOLD` / `ROUND HOLD`) and restarts once the part is taken.
- **Jams:** when the motor stalls, the feeder reverses for about 2 seconds,
  pauses, then feeds forward again (state `JAM`).
- **Repeat jam:** if it jams again within 2 seconds of a recovery, it stops
  in **FAULT** with a **STALL** popup and an alarm. Clear the jam, then tap
  **RESUME**, or block that feeder's sensor twice within 2 seconds.
- **Empty warning:** if nothing has fed for the warning time (30 s by
  default), a popup and a chime say the feeder is empty. It keeps running,
  and the popup clears itself when parts flow again.
- **Auto shutoff:** after 2 minutes with nothing fed, the feeder stops
  (`IDLE`). Reload, then tap **RESUME** or block the sensor twice.
- **Driver temperature:** popups warn as a motor driver passes 120, 143,
  150 and 157 °C, and if it shuts itself off. Check the fan.

### Settings

Tap the gear in the top bar.

| Setting | What it does |
|---|---|
| Alerts | sounds on or off |
| Early warn (Case warn / Bullet warn) | empty-warning time, 15 to 90 s |
| Flip screen | turns the display 180° |
| Machine (press and hold) | CASE, BULLET or DUAL; only while every feeder is stopped |
| Volume | low, medium, high |

### Status light

The controller's RGB LED (and an optional external WS2812) shows the most
urgent feeder:

| Light | Meaning |
|---|---|
| green, steady | running |
| amber, slow blink | part waiting at the sensor |
| orange, fast blink | clearing a jam |
| blue, blinking | auto shutoff (empty) |
| red, flickering | FAULT |
| dim white | stopped, ready |
| red, 1 s blink | a motor driver is not answering (24 V off?) |

## Serial commands

Commands are a letter, a space, and a value (for example `U 1`), followed by
Enter. Feeder commands apply to the **selected** feeder; select it with `U`.

### Setup (saved)

| Command | What it does |
|---|---|
| `?` | full status |
| `K 1` / `K 2` / `K 3` | machine: case / bullet / dual (every feeder stopped first) |
| `U 0` / `U 1` | select the case / bullet feeder for the commands below |
| `R 1` / `R 0` | run / stop the selected feeder |
| `N 0` / `N 1` | sensor reads LOW / HIGH when a part is there |
| `M 0` / `M 1` | motor direction normal / reversed (feeder stopped) |

### Advanced (not saved; reset at power-up)

| Command | What it does |
|---|---|
| `t 1` / `t 0` | telemetry: StallGuard reading, speed and state twice a second |
| `e 1` / `e 0` | log every sensor block and clear |
| `j 1` / `j 0` | jam detection on / off |
| `s <n>` | set every jam threshold of the selected feeder to `n` (trips below `2 x n`) |
| `v <hz>` / `V <hz>` | maximum / minimum step rate (100 % / 0 % speed) |
| `b <ms>` / `B <ms>` | sensor time before a hold / clear time before resuming |
| `C <ms>` | sensor clear time before the next part counts |
| `w <ms>` | repeat-jam window (a jam within it is a FAULT) |
| `W <ms>` | how long a stall must last to count as a jam |
| `d <ms>` | settle time after speeding up before jams are checked |
| `g <hz>` | no jam checks below this step rate |
| `r <hz>` | reverse speed while clearing a jam |
| `o <ms>` / `i <ms>` | empty-warning / auto-shutoff time (0 = off) |
| `a` / `A` / `D <hz/s>` | acceleration / start-up acceleration / deceleration |
| `T` | simulate a jam (while running) |
| `F` | force a FAULT |

## Adjusting jam detection

Jam detection compares the motor driver's StallGuard reading with a
threshold for the current speed: the reading drops when the plate is
loaded, and a stall is flagged below **2 x threshold**. The built-in
thresholds suit the standard case and bullet feeders. If a feeder reports
jams that did not happen, or misses real ones, measure and adjust:

1. Select the feeder (`U 0` / `U 1`), turn jam detection off (`j 0`) and
   telemetry on (`t 1`).
2. Load the feeder and run it at the speed in question. Note the lowest
   `SG` value during normal feeding.
3. Hold the plate to make a jam and note the `SG` value while it is held.
4. Pick a threshold whose double (`trip<`) sits midway between the two
   numbers, set it with `s <n>`, turn detection back on (`j 1`) and test.

`s` is not saved. To keep a new value, edit `CASE_BANDS` or `BULLET_BANDS`
in `src/controller.cpp` (one threshold per speed range) and reflash the
controller.

## Troubleshooting

| Symptom | Check |
|---|---|
| Screen shows `NO LINK` / `CONTROLLER OFFLINE` | controller powered; swap the two data wires; 5V and GND connected |
| `CHECK DRIVER`, or the LED blinks red once a second | 24 V on; the motor driver could not be configured |
| Motor buzzes but does not turn | motor coil pairs (see [Motors](#motors)) |
| Plate turns the wrong way | `M 1` for that feeder |
| Feeder never holds, or holds all the time | sensor wiring; sensor polarity (`N 0` / `N 1`); check with `e 1` |
| Jams are not detected | `?` shows `DIAG in use`; DIAG jumper fitted |
| Jams reported that did not happen, or real jams missed | [Adjusting jam detection](#adjusting-jam-detection) |
| Machine **APPLY** is greyed out | stop every feeder first |
| Screen is upside down | Settings > Flip screen |

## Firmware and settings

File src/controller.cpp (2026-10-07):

// ============================================================
//  Case Feeder Pro - controller firmware
//  BigTreeTech SKR Pico V1.0 (RP2040)
//  Copyright (C) the Case Feeder Pro contributors. Licensed under GPL-3.0.
//
//  Runs a CASE feeder, a BULLET feeder, or both side by side. The MACHINE
//  setting (chosen on the LCD under Settings > Machine, or `K` on serial)
//  says which. Each feeder has fixed ports, so changing the machine never
//  needs rewiring; a feeder that is not part of the machine is held off.
//
//  Each feeder runs independently: its own state machine, beam, jam
//  detection, tuning and settings. A jam, fault or idle shutoff on one never
//  stops the other. The controller owns every real-time and safety
//  behavior; the LCD is optional and the feeders keep running without it.
//
//  Pin map (BTT SKR Pico V1.0):
//    CASE    X driver : STEP 11, DIR 10, EN 12 (TMC UART address 0)
//            DIAG GPIO4  via the X-DIAG jumper onto X-STOP
//            beam GPIO3  on Y-STOP (IO3 / GND / 5V)
//    BULLET  E driver : STEP 14, DIR 13, EN 15 (TMC UART address 3)
//            DIAG GPIO16 via the E0-DIAG jumper onto E0-STOP
//            beam GPIO25 on Z-STOP (IO25 / GND / 5V)
//    GPIO8/9  TMC UART (shared bus)     GPIO0/1  LCD UART (Pi header)
//    GPIO24   status RGB LED            GPIO17   FAN1 (driver fan)
//  Y and Z drivers are unused and held disabled. Jumpers: X-DIAG and E0-DIAG
//  fitted; Y-DIAG and Z-DIAG removed (they would land on the beam inputs).
// ============================================================

#include <Arduino.h>
#include <EEPROM.h>
#include <TMCStepper.h>
#include <Adafruit_NeoPixel.h>
#include "hardware/pwm.h"
#include "hardware/clocks.h"
#include "feeder_protocol.h"

using namespace FeederProtocol;

// ============================================================
//  SHARED PINS / CONSTANTS
// ============================================================
static constexpr uint8_t PIN_TMC_TX = 8;    // UART1
static constexpr uint8_t PIN_TMC_RX = 9;
static constexpr uint8_t PIN_RGB    = 24;
static constexpr uint8_t PIN_FAN    = 17;
static constexpr uint8_t PIN_LCD_TX = 0;    // UART0, Pi header
static constexpr uint8_t PIN_LCD_RX = 1;
static constexpr uint8_t PINS_UNUSED_DRIVER_EN[] = { 7, 2 };            // Y, Z
static constexpr uint8_t PINS_PARKED_LOW[]       = { 21, 23, 18, 20 };  // HB, HE, FAN2, FAN3

static constexpr float    R_SENSE           = 0.11f;
static constexpr uint16_t MICROSTEPS        = 16;
static constexpr uint16_t RMS_CURRENT_MA    = 950;     // the jam thresholds are set at this current
static constexpr float    HOLD_CURRENT_MULT = 1.0f;
static constexpr uint32_t STEALTH_CALIBRATE_MS = 150;  // StealthChop settles before stepping
static constexpr uint32_t TCOOLTHRS_VALUE   = 0xFFFFF;
static constexpr uint32_t SPEED_HZ_CEILING  = 15000;
static constexpr uint32_t RAMP_PERIOD_MS    = 10;
static constexpr uint32_t JAM_PAUSE_MS      = 400;
static constexpr uint32_t STALL_CLEAR_MS    = 150;
static constexpr uint32_t SG_SAMPLE_MS      = 100;
static constexpr uint8_t  BEAM_RESET_BREAKS = 2;
static constexpr uint32_t BEAM_RESET_TIMEOUT_MS = 2000;
static constexpr uint32_t STATUS_PERIOD_MS  = 500;
static constexpr uint32_t LCD_TIMEOUT_MS    = 3000;
static constexpr uint32_t DRIVER_RECHECK_MS = 250;
static constexpr uint32_t TELEMETRY_PERIOD_MS = 500;
static constexpr uint32_t LOOP_WDT_MS       = 2000;
static constexpr uint32_t TEMP_SAMPLE_MS    = 1000;
static constexpr uint8_t  LED_BRIGHTNESS    = 40;
static constexpr uint8_t  NUM_FEEDERS       = 2;
static constexpr uint8_t  MAX_BANDS         = 6;

// Jam detection threshold by speed. The TMC2209 flags a stall when its
// StallGuard reading drops below 2 x SGTHRS; the reading rises with speed, so
// each speed range gets its own threshold.
struct StallBand {
    uint32_t speedMinHz;
    uint8_t  threshold;   // SGTHRS
};

// ============================================================
//  PER-MACHINE TUNING
// ============================================================
struct FeederConfig {
    const char* name;
    char        tag;              // prefix on serial log lines
    uint8_t     productType;
    uint8_t     gearbox;
    uint8_t     pinStep, pinDir, pinEnN, pinDiag, pinBeam;
    uint8_t     driverAddr;
    uint32_t    speedMinHz, speedMaxHz;
    uint32_t    jamReverseMs, jamReverseHz, jamMinSpeedHz;
    uint32_t    decelHzPerSec;
    uint16_t    beamConfirmMs, beamClearMs;
    const StallBand* bands;
    uint8_t     numBands;
};

// Case feeder, 51:1 gearbox.
static const StallBand CASE_BANDS[] = { { 0, 140 }, { 9298, 150 }, { 10729, 160 } };
static const FeederConfig CASE_CFG = {
    "CASE", 'C', PRODUCT_CASE, 51, 11, 10, 12, 4, 3, 0,
    7868, 12875, 2300, 10729, 4292, 28610, 250, 1500, CASE_BANDS, 3 };

// Bullet feeder, 51:1 gearbox. Bullet jams load the motor less than case
// jams, so its thresholds sit closer to the normal running reading.
static const StallBand BULLET_BANDS[] = {
    { 0, 168 }, { 7438, 173 }, { 8583, 177 }, { 9727, 182 }, { 10871, 186 } };
static const FeederConfig BULLET_CFG = {
    "BULLET", 'B', PRODUCT_BULLET, 51, 14, 13, 15, 16, 25, 3,
    5722, 11444, 2300, 7153, 2504, 21458, 150, 1000, BULLET_BANDS, 5 };

// ============================================================
//  SAVED SETTINGS (EEPROM emulation in flash)
// ============================================================
struct PersistData {
    uint32_t magic;
    uint16_t version;
    uint8_t  machineMask;                  // MachineMask
    uint8_t  beamActiveHigh[NUM_FEEDERS];
    uint8_t  motorReversed[NUM_FEEDERS];
    uint16_t warnSeconds[NUM_FEEDERS];
    uint8_t  speedPercent[NUM_FEEDERS];    // last speed, restored at power-up
};
static constexpr uint8_t  DEFAULT_SPEED_PERCENT = 60;   // a new board; one of the LCD presets
static constexpr uint32_t PERSIST_MAGIC   = 0x31524446u;   // "FDR1"
static constexpr uint16_t PERSIST_VERSION = 2;
static PersistData persist;
static PersistData persistSaved;

static void persistDefaults() {
    memset(&persist, 0, sizeof(persist));
    persist.magic       = PERSIST_MAGIC;
    persist.version     = PERSIST_VERSION;
    persist.machineMask = MACHINE_DUAL;    // a new board shows both; pick on the LCD
    for (uint8_t i = 0; i < NUM_FEEDERS; i++) {
        persist.warnSeconds[i]  = 30;
        persist.speedPercent[i] = DEFAULT_SPEED_PERCENT;
    }
}

// Each write erases a flash sector (~50 ms, interrupts off), so save only
// when a setting actually changes.
static void persistSave() {
    if (memcmp(&persist, &persistSaved, sizeof(persist)) == 0) return;
    EEPROM.put(0, persist);
    EEPROM.commit();
    persistSaved = persist;
}

static void persistLoad() {
    EEPROM.begin(256);
    EEPROM.get(0, persist);
    persistSaved = persist;
    if (persist.magic != PERSIST_MAGIC || persist.version != PERSIST_VERSION ||
        persist.machineMask == 0 || (persist.machineMask & ~MACHINE_DUAL)) {
        persistDefaults();
        persistSave();
    }
}

static const char* stateName(uint8_t s) {
    switch (s) {
        case STATE_RUNNING:      return "RUNNING";
        case STATE_BEAM_BLOCKED: return "BEAM_BLOCKED";
        case STATE_JAM_REVERSE:  return "JAM_REVERSE";
        case STATE_JAM_PAUSE:    return "JAM_PAUSE";
        case STATE_PAUSED:       return "PAUSED";
        case STATE_FAULT:        return "FAULT";
        case STATE_IDLE_SHUTOFF: return "IDLE_SHUTOFF";
        default:                 return "?";
    }
}

// ============================================================
//  FEEDER STATE
// ============================================================
struct Feeder {
    uint8_t             index;
    const FeederConfig* cfg;
    TMC2209Stepper*     drv;
    bool                enabled;      // part of this board's machine

    // runtime tuning (serial-adjustable, not saved)
    uint32_t  speedMinHz, speedMaxHz;
    uint32_t  accelHzPerSec, startupAccelHzPerSec, decelHzPerSec;
    uint32_t  jamReverseHz, jamMinSpeedHz;
    uint16_t  jamRepeatWindowMs, stallConfirmMs, stallSettleMs;
    uint16_t  beamConfirmMs, beamClearMs, countClearMs;
    uint32_t  idleWarnMs, idleShutoffMs;
    StallBand bands[MAX_BANDS];
    uint8_t   numBands;

    // motion
    State     state;
    uint32_t  stateSince;
    bool      driverReady, motorPowered, useSlowStart;
    uint32_t  appliedHz, targetHz;
    bool      motorReversed, dirForward;
    int8_t    appliedDirLevel;
    uint32_t  motorEnabledAt, lastRampAt;
    uint      stepSlice, stepChannel;
    bool      runRequested;
    uint8_t   speedPercent;

    // beam / count / idle
    bool      beamActiveLow;
    bool      beamBlocked, rawBeam;
    uint32_t  beamBrokenSince, beamClearedSince, beamClearSince;
    bool      countArmed, prevBeamRunning;
    uint16_t  count;
    uint32_t  lastFedTime;
    bool      idleWarnActive, idleWarnDismissed;
    uint8_t   beamResetBreaks;
    uint32_t  beamResetStart;
    bool      prevBeamState;
    bool      edgePrev;
    uint32_t  edgeStart, edgeClearStart;

    // stall
    bool      stallActive, jamDetect, diagUsable;
    uint32_t  stallTimer, lastStallEvent, stallSettleStart, lastRecoveryEnd;
    uint16_t  sgResult, sgWindowMin, sgWindowMax;
    int8_t    currentStallBand;
    uint8_t   appliedSgThreshold;

    // health / temperature
    uint32_t  lastDriverCheck, lastSgRead;
    uint8_t   resetReads;
    bool      offlineLogged;
    uint8_t   driverTempLevel, driverTempPending;
    uint32_t  lastFaultPrint, lastIdlePrint;
};

static SerialUART& TMCSerial = Serial2;
static SerialUART& LCDSerial = Serial1;
TMC2209Stepper drvCase(&TMCSerial, R_SENSE, CASE_CFG.driverAddr);
TMC2209Stepper drvBullet(&TMCSerial, R_SENSE, BULLET_CFG.driverAddr);
Adafruit_NeoPixel statusPixel(1, PIN_RGB, NEO_GRB + NEO_KHZ800);

static Feeder feeders[NUM_FEEDERS];
static uint8_t selected = 0;           // serial tuning commands apply to this feeder

static uint32_t lastStatusAt = 0, lastLcdRxAt = 0, lastTelemetry = 0, lastTempAt = 0;
static bool     telemetryOn = false, beamLogOn = false;
static float    boardTempC = NAN;

struct RxParser {
    enum Stage : uint8_t { WAIT_SOF, READ_LEN, READ_BODY, CRC_LOW, CRC_HIGH, WAIT_EOF } stage = WAIT_SOF;
    uint8_t length = 0;
    uint8_t index = 0;
    uint8_t body[MAX_PAYLOAD + 1]{};
    uint16_t receivedCrc = 0;
} rx;

static void writeFrame(uint8_t command, const void* payload = nullptr, uint8_t payloadLength = 0);

static void feederInit(Feeder& f, uint8_t index, const FeederConfig* cfg, TMC2209Stepper* drv) {
    memset(&f, 0, sizeof(f));
    f.index = index;
    f.cfg   = cfg;
    f.drv   = drv;
    f.speedMinHz = cfg->speedMinHz;
    f.speedMaxHz = cfg->speedMaxHz;
    f.accelHzPerSec = 143051;
    f.startupAccelHzPerSec = 35763;
    f.decelHzPerSec = cfg->decelHzPerSec;
    f.jamReverseHz  = cfg->jamReverseHz;
    f.jamMinSpeedHz = cfg->jamMinSpeedHz;
    f.jamRepeatWindowMs = 2000;
    f.stallConfirmMs = 450;
    f.stallSettleMs  = 300;
    f.beamConfirmMs  = cfg->beamConfirmMs;
    f.beamClearMs    = cfg->beamClearMs;
    f.countClearMs   = 30;
    f.idleWarnMs     = 30000;
    f.idleShutoffMs  = 120000;
    f.numBands = cfg->numBands;
    for (uint8_t i = 0; i < cfg->numBands; i++) f.bands[i] = cfg->bands[i];
    f.state = STATE_PAUSED;
    f.useSlowStart = true;
    f.dirForward = true;
    f.appliedDirLevel = -1;
    f.speedPercent = DEFAULT_SPEED_PERCENT;
    f.beamActiveLow = true;
    f.countArmed = true;
    f.jamDetect = true;
    f.currentStallBand = -1;
    f.sgWindowMin = 0xFFFF;
}

// ============================================================
//  MOTOR CONTROL - step pulses from a hardware PWM slice
// ============================================================
static void stepPwmInit(Feeder& f) {
    gpio_set_function(f.cfg->pinStep, GPIO_FUNC_PWM);
    f.stepSlice   = pwm_gpio_to_slice_num(f.cfg->pinStep);
    f.stepChannel = pwm_gpio_to_channel(f.cfg->pinStep);
    pwm_set_chan_level(f.stepSlice, f.stepChannel, 0);
    pwm_set_enabled(f.stepSlice, true);
}

static void setStepFrequency(Feeder& f, uint32_t hz) {
    if (hz == f.appliedHz) return;
    f.appliedHz = hz;
    if (hz == 0) { pwm_set_chan_level(f.stepSlice, f.stepChannel, 0); return; }
    const uint32_t sysHz = clock_get_hz(clk_sys);
    uint32_t div = sysHz / (hz * 65536UL) + 1;
    if (div > 255) div = 255;
    uint32_t top = sysHz / (div * hz);
    if (top < 2)     top = 2;
    if (top > 65536) top = 65536;
    pwm_set_clkdiv_int_frac(f.stepSlice, (uint8_t)div, 0);
    pwm_set_wrap(f.stepSlice, (uint16_t)(top - 1));
    pwm_set_chan_level(f.stepSlice, f.stepChannel, (uint16_t)(top / 2));
}

static void motorEnable(Feeder& f, bool enable) {
    if (enable) {
        if (!f.motorPowered) {
            f.motorPowered   = true;
            f.motorEnabledAt = millis();
            f.lastRampAt     = f.motorEnabledAt;
            setStepFrequency(f, 0);
            digitalWrite(f.cfg->pinEnN, LOW);
        }
    } else {
        f.targetHz = 0;
        setStepFrequency(f, 0);
        digitalWrite(f.cfg->pinEnN, HIGH);
        f.motorPowered = false;
    }
}

static void stopImmediately(Feeder& f) {
    motorEnable(f, false);
    f.useSlowStart = true;
}

static void setDirection(Feeder& f, bool forward) {
    f.dirForward = forward;
    const int8_t level = (forward != f.motorReversed) ? HIGH : LOW;
    if (level == f.appliedDirLevel) return;
    f.appliedDirLevel = level;
    digitalWrite(f.cfg->pinDir, level);
}

static uint32_t selectedStepHz(const Feeder& f) {
    return f.speedMinHz + ((f.speedMaxHz - f.speedMinHz) * f.speedPercent) / 100U;
}

// Walk the step rate toward the target: gentle acceleration on a fresh
// start, normal acceleration otherwise, and a fast deceleration.
static void serviceMotorRamp(Feeder& f) {
    if (!f.motorPowered) return;
    const uint32_t now = millis();
    if (now - f.motorEnabledAt < STEALTH_CALIBRATE_MS) { f.lastRampAt = now; return; }
    if (f.appliedHz == f.targetHz) { f.lastRampAt = now; return; }
    uint32_t dt = now - f.lastRampAt;
    if (dt < RAMP_PERIOD_MS) return;
    if (dt > 100) dt = 100;
    f.lastRampAt = now;
    const bool decel = f.targetHz < f.appliedHz;
    const uint32_t rate = decel ? f.decelHzPerSec
                                : (f.useSlowStart ? f.startupAccelHzPerSec : f.accelHzPerSec);
    uint32_t delta = (uint32_t)(((uint64_t)rate * dt) / 1000U);
    if (delta == 0) delta = 1;
    const uint32_t prevHz = f.appliedHz;
    uint32_t next = f.appliedHz;
    if (next < f.targetHz) next += min(delta, f.targetHz - next);
    else                   next -= min(delta, next - f.targetHz);
    setStepFrequency(f, next);
    if (prevHz <= f.jamMinSpeedHz && f.appliedHz > f.jamMinSpeedHz) f.stallSettleStart = now;
    if (f.useSlowStart && f.appliedHz >= f.targetHz) f.useSlowStart = false;
}

static void serviceStallThreshold(Feeder& f) {
    if (!f.driverReady) return;
    int8_t band = 0;
    for (int8_t i = f.numBands - 1; i >= 0; i--) {
        if (f.appliedHz >= f.bands[i].speedMinHz) { band = i; break; }
    }
    if (band == f.currentStallBand && f.bands[band].threshold == f.appliedSgThreshold) return;
    f.currentStallBand   = band;
    f.appliedSgThreshold = f.bands[band].threshold;
    f.drv->SGTHRS(f.appliedSgThreshold);
}

// A stall shows either on the DIAG line (instant) or in the polled reading.
static bool isStalled(Feeder& f) {
    const uint16_t trip = (uint16_t)f.appliedSgThreshold * 2U;
    if (f.sgResult > 0 && f.sgResult < trip) return true;
    return f.diagUsable && digitalRead(f.cfg->pinDiag) == HIGH;
}

// ============================================================
//  BEAM
// ============================================================
static bool readBeamRaw(Feeder& f) {
    const bool low = digitalRead(f.cfg->pinBeam) == LOW;
    return f.beamActiveLow ? low : !low;
}

// Two quick beam breaks (within BEAM_RESET_TIMEOUT_MS) resume a feeder
// from FAULT or idle shutoff without the LCD.
static bool checkBeamResetGesture(Feeder& f) {
    const bool blocked = readBeamRaw(f);
    bool done = false;
    if (blocked && !f.prevBeamState) {
        if (f.beamResetBreaks == 0) f.beamResetStart = millis();
        f.beamResetBreaks++;
        Serial.printf("%c Reset gesture: break %u/%u\n", f.cfg->tag, f.beamResetBreaks, BEAM_RESET_BREAKS);
        if (f.beamResetBreaks >= BEAM_RESET_BREAKS) { f.beamResetBreaks = 0; done = true; }
    }
    f.prevBeamState = blocked;
    if (f.beamResetBreaks > 0 && millis() - f.beamResetStart > BEAM_RESET_TIMEOUT_MS) f.beamResetBreaks = 0;
    return done;
}

static void serviceBeam(Feeder& f) {
    const bool blocked = readBeamRaw(f);
    if (beamLogOn) {
        if (blocked && !f.edgePrev) {
            f.edgeStart = millis();
            if (f.edgeClearStart) Serial.printf("%c BEAM broken after %lu ms clear\n", f.cfg->tag,
                                                (unsigned long)(millis() - f.edgeClearStart));
            else                  Serial.printf("%c BEAM broken\n", f.cfg->tag);
        } else if (!blocked && f.edgePrev) {
            Serial.printf("%c BEAM cleared after %lu ms\n", f.cfg->tag, (unsigned long)(millis() - f.edgeStart));
            f.edgeClearStart = millis();
        }
    }
    f.edgePrev = blocked;
    f.rawBeam  = blocked;

    // Count each part once, on the leading edge of a break.
    if (blocked && !f.prevBeamRunning) {
        f.lastFedTime       = millis();
        f.idleWarnActive    = false;
        f.idleWarnDismissed = false;
        if (f.countArmed) {
            f.countArmed = false;
            f.count++;
            uint8_t evt[3];
            memcpy(evt, &f.count, 2);
            evt[2] = f.index;
            writeFrame(EVT_COUNT, evt, 3);
        }
    }
    if (!blocked) {
        if (f.beamClearSince == 0) f.beamClearSince = millis();
        if (!f.countArmed && millis() - f.beamClearSince >= f.countClearMs) f.countArmed = true;
    } else {
        f.beamClearSince = 0;
    }
    f.prevBeamRunning = blocked;

    // "Blocked" (hold the motor) only after a sustained break, and released
    // only after a sustained clear.
    if (blocked) {
        f.beamClearedSince = 0;
        if (f.beamBrokenSince == 0) f.beamBrokenSince = millis();
        else if (!f.beamBlocked && millis() - f.beamBrokenSince >= f.beamConfirmMs) f.beamBlocked = true;
    } else {
        f.beamBrokenSince = 0;
        if (f.beamBlocked) {
            if (f.beamClearedSince == 0) f.beamClearedSince = millis();
            else if (millis() - f.beamClearedSince >= f.beamClearMs) {
                f.beamBlocked = false;
                f.beamClearedSince = 0;
            }
        }
    }
}

// ============================================================
//  STATUS LED - shows the most urgent feeder
// ============================================================
static uint8_t urgency(const Feeder& f) {
    switch (f.state) {
        case STATE_FAULT:        return 6;
        case STATE_JAM_REVERSE:
        case STATE_JAM_PAUSE:    return 5;
        case STATE_IDLE_SHUTOFF: return 4;
        case STATE_BEAM_BLOCKED: return 3;
        case STATE_RUNNING:      return 2;
        default:                 return 1;
    }
}

static void serviceLed() {
    static uint32_t shown = 0xFFFFFFFFu;
    const uint32_t now = millis();
    const Feeder* worst = nullptr;
    bool driversOk = true;
    for (const Feeder& g : feeders) {
        if (!g.enabled) continue;
        if (!worst || urgency(g) > urgency(*worst)) worst = &g;
        if (!g.driverReady) driversOk = false;
    }
    if (!worst) return;
    uint32_t colour = 0;
    switch (worst->state) {
        case STATE_RUNNING:      colour = 0x00FF00; break;
        case STATE_BEAM_BLOCKED: colour = ((now / 500U) & 1U) ? 0xFFA000 : 0; break;
        case STATE_JAM_REVERSE:
        case STATE_JAM_PAUSE:    colour = ((now / 125U) & 1U) ? 0xFF4000 : 0; break;
        case STATE_IDLE_SHUTOFF: colour = ((now / 250U) & 1U) ? 0x0040FF : 0; break;
        case STATE_FAULT:        colour = ((now / 75U)  & 1U) ? 0xFF0000 : 0; break;
        default:                 colour = 0x303030; break;
    }
    if (!driversOk) colour = ((now / 1000U) & 1U) ? 0xFF0000 : 0;
    if (colour == shown) return;
    shown = colour;
    statusPixel.setPixelColor(0, colour);
    statusPixel.show();
}

// ============================================================
//  LCD LINK
// ============================================================
static void writeFrame(uint8_t command, const void* payload, uint8_t payloadLength) {
    if (payloadLength > MAX_PAYLOAD) return;
    uint8_t frame[MAX_PAYLOAD + 7];
    size_t i = 0;
    frame[i++] = SOF;
    frame[i++] = (uint8_t)(payloadLength + 1);
    frame[i++] = command;
    if (payloadLength && payload) { memcpy(&frame[i], payload, payloadLength); i += payloadLength; }
    const uint16_t crc = crc16(&frame[1], payloadLength + 2);
    frame[i++] = (uint8_t)crc;
    frame[i++] = (uint8_t)(crc >> 8);
    frame[i++] = EOF_MARKER;
    LCDSerial.write(frame, i);
}
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
void loop() {
    rp2040.wdt_reset();
    serviceLcd();
    for (Feeder& f : feeders) if (f.enabled) serviceBeam(f);
    for (Feeder& f : feeders) if (f.enabled) serviceStateMachine(f);
    for (Feeder& f : feeders) if (f.enabled) serviceMotorRamp(f);
    for (Feeder& f : feeders) if (f.enabled) serviceStallThreshold(f);
    for (Feeder& f : feeders) if (f.enabled) checkDriverHealth(f);

    for (Feeder& f : feeders) {
        if (f.enabled && f.driverReady && f.state == STATE_RUNNING && millis() - f.lastSgRead >= SG_SAMPLE_MS) {
            f.lastSgRead = millis();
            f.sgResult = f.drv->SG_RESULT();
            if (f.sgResult < f.sgWindowMin) f.sgWindowMin = f.sgResult;
            if (f.sgResult > f.sgWindowMax) f.sgWindowMax = f.sgResult;
        }
    }

    serviceLed();
    handleSerial();
    serviceTemps();
    updateTelemetry();
}

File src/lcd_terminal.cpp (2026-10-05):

// ============================================================
//  Case Feeder Pro - LCD firmware
//  LCDWiki ES3C28P 2.8" ESP32-S3 display (ILI9341 + FT6336 touch)
//  Copyright (C) the Case Feeder Pro contributors. Licensed under GPL-3.0.
//
//  The touchscreen for the controller. It lays itself out from what the
//  controller reports:
//    - one feeder:  the full single screen, titled CASE FEEDER PRO or
//                   BULLET FEEDER PRO (speed presets, rate, TEMP, STOP/GO)
//    - two feeders: DUAL FEEDER PRO, split in halves - CASE left, BULLET
//                   right, each with - / + speed, rate and its own STOP/GO
//  Settings > Machine (press and hold) switches the controller between case,
//  bullet and dual; the screen follows on its own. The last layout is
//  remembered so the right screen comes up at power-on.
//
//  The LCD displays state, offers touch control and sounds the alerts. The
//  controller owns all motor and safety behavior and keeps running if the
//  LCD is unplugged or restarting.
//
//  Link: 115200 8-N-1 on GPIO43 (TX) / GPIO44 (RX).
// ============================================================

#include <Arduino.h>
#include <Preferences.h>
#include <esp_system.h>
#include <lvgl.h>
#include "lvgl_driver.h"
#include "audio_manager.h"
#include "feeder_protocol.h"
#include "lcd_assert_hook.h"

using namespace FeederProtocol;

static constexpr uint8_t  PIN_CONTROLLER_TX = 43;
static constexpr uint8_t  PIN_CONTROLLER_RX = 44;
static constexpr uint32_t CONNECTION_TIMEOUT_MS = 3000;
#define FW_VERSION "1.0.0"

// LVGL calls this on an internal error; restart instead of hanging.
extern "C" void lcd_lvgl_assert_hook(void) {
    esp_restart();
}

HardwareSerial ControllerSerial(1);
AudioManager   audio;

// ---- Theme ----------------------------------------------------------------
#define COL_SCR_BG     0x0C0F14
#define COL_BAR_BG     0x151B24
#define COL_PANEL_BG   0x121822
#define COL_PANEL_BRD  0x2C3E55
#define COL_TAB_BG     0x2B6CB0
#define COL_TEXT       0xFFFFFF
#define COL_MUTED      0x8A97A6
#define COL_GREEN      0x39D353
#define COL_AMBER      0xFFB300
#define COL_REDST      0xFF5252
#define COL_RED_TOP    0xE5453C
#define COL_RED_BOT    0xB5271F
#define COL_GRN_TOP    0x43A047
#define COL_GRN_BOT    0x2E7D32
#define COL_GRY_TOP    0x6B7280
#define COL_GRY_BOT    0x434954
#define COL_SIL_TOP    0xFBFCFD
#define COL_SIL_BOT    0xC2C8D0
#define COL_SIL_BRD    0x9AA2AD
#define COL_SIL_TXT    0x161A1F
#define COL_SEL_TOP    0x5AA7F0
#define COL_SEL_BOT    0x1E6FD0
#define COL_SEL_BRD    0x1257A8
#define COL_PURPLE     0xAB47BC

#define NUM_SPEED_PRESETS 5
static const uint8_t SPEED_PRESETS[NUM_SPEED_PRESETS] = { 20, 40, 60, 80, 100 };
#define WARN_STEP_SECONDS 15
#define NUM_WARN_OPTIONS  6                // 15..90 s

// Rate (parts per hour): rolling window over recent counts.
#define RATE_RING        64
#define RATE_WINDOW_MS   30000UL
#define RATE_DECAY_GRACE 2
#define RATE_ROUND       25

// ---- Per-feeder data + its widgets on the current screen ------------------
struct FeederView {
    StatusPayload st;
    uint8_t  product;          // ProductType, from the controller
    bool     have;
    uint32_t lastFrameAt;
    uint32_t fedTimes[RATE_RING];
    uint8_t  ringHead, ringLen;
    uint16_t lastSeenCount;
    bool     haveSeenCount;
    float    rateSmoothed;
    uint32_t lastRateAt;
    // widgets (null when this feeder is not on screen)
    lv_obj_t *stateLed, *stateLbl, *speedVal, *speedBar, *rateLbl, *goBtn, *goLbl;
    lv_obj_t *stallModal, *idleModal, *warnModal;
    // refresh cache
    bool     warnDismissed, warnShown;
    int      lastState, lastFlags, lastPct, lastHave, lastRate;
};
static FeederView views[MAX_FEEDERS];

// What the screen shows: a MachineMask (which feeders), plus the product of
// the single feeder.
static uint8_t uiShown   = 0;
static uint8_t uiProduct = PRODUCT_CASE;
static uint8_t wantShown = MACHINE_CASE, wantProduct = PRODUCT_CASE;
static bool isDual()       { return uiShown == MACHINE_DUAL; }
static uint8_t singleIdx() { return uiShown == MACHINE_BULLET ? 1 : 0; }
static bool shownOnScreen(uint8_t i) { return (uiShown >> i) & 1U; }

static uint32_t lastValidFrameAt = 0, lastPingAt = 0, lastStatusRequestAt = 0;
static bool     audioEnabled = true;
static int      audioVolume  = 2;

// Shared widgets
static lv_obj_t *ui_tempLabel, *ui_healthLbl, *ui_linkLed, *ui_linkLbl;
static lv_obj_t *ui_settingsModal, *ui_audioSwitch, *ui_flipSwitch, *ui_machineBtnLbl;
static lv_obj_t *ui_warnDd[MAX_FEEDERS];
static lv_obj_t *ui_volBtns[3], *ui_volLbls[3];
static lv_obj_t *ui_tempModal, *ui_tempBox, *ui_tempTitle, *ui_tempMsg;
static lv_obj_t *ui_resetModal, *ui_resetTitle;
static uint8_t   resetTarget = 0;
static lv_obj_t *ui_machineModal, *ui_machineOpt[3], *ui_machineOptLbl[3], *ui_machineInfo,
                *ui_machineNote, *ui_machineApply;
static uint8_t   machineChoice = MACHINE_CASE;
static lv_obj_t *ui_speedBtns[NUM_SPEED_PRESETS], *ui_speedBtnLbls[NUM_SPEED_PRESETS];   // single screen
// Shared refresh cache
static int      sharedLastLink = -1, sharedLastTemp = INT16_MIN + 1;
static char     sharedLastHealth[40] = "";
static uint8_t  tempAckLevel = 0, shownTempLevel = 0;
static int      shownTempWho = -1;

struct RxParser {
    enum Stage : uint8_t { WAIT_SOF, READ_LEN, READ_BODY, CRC_LOW, CRC_HIGH, WAIT_EOF } stage = WAIT_SOF;
    uint8_t length = 0, index = 0;
    uint8_t body[MAX_PAYLOAD + 1]{};
    uint16_t receivedCrc = 0;
} rx;

// ---- Wording by product -----------------------------------------------------
static bool isBullet(uint8_t product) { return product == PRODUCT_BULLET; }
static const char* nameOf(const FeederView& v)    { return isBullet(v.product) ? "BULLET" : "CASE"; }
static const char* rateTabOf(const FeederView& v) { return isBullet(v.product) ? "BULLETS/HR" : "CASES/HR"; }
static const char* holdOf(const FeederView& v)    { return isBullet(v.product) ? "ROUND HOLD" : "CASE HOLD"; }
static const char* nounOf(const FeederView& v)    { return isBullet(v.product) ? "bullets" : "cases"; }

// ---- Link -------------------------------------------------------------------
static void sendFrame(uint8_t command, const void* payload = nullptr, uint8_t payloadLength = 0) {
    if (payloadLength > MAX_PAYLOAD) return;
    uint8_t frame[MAX_PAYLOAD + 7];
    size_t i = 0;
    frame[i++] = SOF;
    frame[i++] = (uint8_t)(payloadLength + 1);
    frame[i++] = command;
    if (payloadLength && payload) { memcpy(&frame[i], payload, payloadLength); i += payloadLength; }
    const uint16_t crc = crc16(&frame[1], payloadLength + 2);
    frame[i++] = (uint8_t)crc;
    frame[i++] = (uint8_t)(crc >> 8);
    frame[i++] = EOF_MARKER;
    ControllerSerial.write(frame, i);
}
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

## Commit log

2026-10-05 Case Feeder Pro firmware and build guide
    Controller firmware for the BTT SKR Pico (case, bullet or dual feeder,
    chosen on the touchscreen) and touchscreen firmware for the LCDWiki
    ES3C28P, with a build guide and parts list template.
2026-10-05 Build guide: color-coded SKR Pico connection diagram
2026-10-05 Build guide: beam emitters take 5V/GND from any 5V connector
2026-10-05 Docs: one part sensor per feeder, IR or break-beam
2026-10-05 Parts list: 24 V 6 A power supply
2026-10-05 Parts list: power supply 3 to 6 A
2026-10-05 Parts list: change power supply link
2026-10-05 Parts list: linked power supply is 3 A
2026-10-05 Parts list: 12 x 3 mm magnets
2026-10-05 Parts list: screws, nuts, inserts and magnet use
2026-10-05 Parts list: case feeder hardware, ABS outer wall
2026-10-05 Parts list: bullet feeder hardware; bullet feeder uses the IR sensor
2026-10-05 README: case feeder renders
2026-10-05 README: controller case renders
2026-10-05 Parts list: controller case hardware
2026-10-06 Parts list: 3/16 in ABS sheet for the milled feeder plate
2026-10-06 Parts list: milling the case feeder plate is optional
2026-10-06 Parts list: case feeder plate size and bed needed to print it
2026-10-06 Add STL files and a printed parts list
    [ABS Feeder Plate Milled.stl, ABS Outer v5.stl, ABS outer shell Wrap.stl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]
2026-10-06 Printed parts: base mount options, ramp x4, PEX tube guide, arm mount; rename exit parts
    [Feeder Exit.stl, PEX Tube.stl]
2026-10-06 License the 3D models CC BY-NC-SA 4.0; rename the PEX funnel exit
    [Funnel Exit PEX.stl]
2026-10-06 Case feeder: flat cutting pattern for the ABS outer wall
    [ABS Outer v5 Flat.dxf]
2026-10-06 Bullet feeder: flat cutting pattern for the ABS outer wall
    [ABS outer shell Wrap Flat.dxf]
2026-10-06 Docs: SKR Pico uses JST-XH connectors; cables need to be made
2026-10-06 Docs: touchscreen cable comes with Dupont connectors
2026-10-06 Docs: the Pi UART connector is a 5-pin JST-XH
2026-10-07 Remember each feeder's speed across power-up; 60% on a new board
    The speed was not saved and started at 50%, which is not one of the
    touchscreen presets. Settings layout is now version 2.
2026-10-07 Parts list: only half a shaft coupler is used per feeder
2026-10-07 Parts list: one shaft coupler covers a dual build; TCRT5000 is bullet feeder only
2026-10-07 Case feeder: one-piece bowl STL and STEP model of the milled plate
    [1 piece Bowl.stl, ABS Feeder Plate Milled.step]
2026-10-08 Printed parts: Screw Attachment is the LCD mount
2026-10-08 Add exploded views to the README and printed parts list
2026-10-08 Add the interactive exploded 3D viewer (docs/viewer)
    Standalone page with copies of the models aligned for display; served by
    GitHub Pages from /docs once enabled.
    [abs-outer-shell-wrap.stl, base-angle.stl, base-mount.stl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]
2026-11-02 Add files via upload
    Square post mount bracket for controller case
